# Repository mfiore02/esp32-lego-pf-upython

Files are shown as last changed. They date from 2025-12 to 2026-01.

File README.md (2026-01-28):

# ESP32 Lego Power Functions Controller

MicroPython implementation of a wireless Lego Power Functions motor controller system using ESP32-C3 and ESP-NOW.

## Overview

This project implements a low-latency wireless control system for Lego Power Functions motors, consisting of:

- **Handheld Controller**: Potentiometer for speed, button for direction toggle, 2xAA powered
- **Train Receiver**: Dual TB6612 motor driver, 2S LiPo with USB-C charging, fits in 8x4 stud Lego box
- **Communication**: ESP-NOW protocol for <10ms latency
- **Pairing**: Button-based pairing with MAC addresses stored in NVS flash

## System Architecture

```
┌─────────────────────┐                    ┌─────────────────────┐
│  CONTROLLER         │                    │  TRAIN RECEIVER     │
│  (Handheld)         │   ESP-NOW (WiFi)   │  (On Train)         │
├─────────────────────┤◄──────────────────►├─────────────────────┤
│ • Potentiometer     │   20Hz updates     │ • TB6612 Driver     │
│ • Direction Button  │   Low latency      │ • 2x Motors         │
│ • Status LED        │   Paired MAC       │ • Pair Button       │
│ • 2xAA Power        │   filtering        │ • 2S LiPo + BMS     │
└─────────────────────┘                    └─────────────────────┘
```

## Project Structure

```
esp32-lego-pf-upython/
├── lib/                          # Shared modules (both devices)
│   ├── espnow_protocol.py        # ESP-NOW wrapper + message protocol
│   ├── config_manager.py         # NVM storage abstraction (versioned)
│   ├── button.py                 # Debounced button driver
│   ├── led.py                    # LED patterns (solid, blink, etc)
│   ├── motor_driver.py           # TB6612 abstraction
│   ├── potentiometer.py          # ADC with dead zone handling
│   ├── battery.py                # 2S LiPo voltage monitoring (receiver)
│   └── hardware.py               # GPIO pin assignments (both devices)
│
├── controller/
│   ├── boot.py                   # Minimal - sets up path
│   └── main.py                   # Controller app entry point
│
├── receiver/
│   ├── boot.py                   # Minimal - sets up path
│   └── main.py                   # Receiver app entry point
│
├── tests/                        # Unit tests (run on host)
│   ├── test_espnow_protocol.py
│   ├── test_config_manager.py
│   └── test_potentiometer.py
│
├── hwil/                         # Hardware-in-loop test scripts
│   ├── test_button.py            # Flash to device, test button
│   ├── test_motors.py
│   └── test_espnow_ping.py
│
├── tools/
│   ├── flash_controller.sh       # Deploy to controller
│   ├── flash_receiver.sh         # Deploy to receiver
│   └── cli.py                    # USB-C serial config tool
│
├── docs/
│   └── lego_pf_controller_build_guide.pdf
│
└── README.md
```

## Hardware Requirements

### Train Receiver (Per-unit cost: $26-36)
- ESP32-C3 SuperMini
- TB6612FNG dual H-bridge motor driver
- USB-C 2S BMS (balanced charging)
- 2S LiPo 350mAh (45×15×14mm with balance lead)
- AMS1117-3.3V voltage regulator
- Mini slide switch (SPST, 3A+)
- Momentary pushbutton (or use onboard BOOT button)
- 2x Lego PF extension cables
- Prototype board and wiring

### Handheld Controller (Per-unit cost: $8-15)
- ESP32-C3 SuperMini
- 10K potentiometer (linear, panel mount)
- Knob for potentiometer
- Momentary pushbutton (direction + pairing)
- 2xAA battery holder
- SPST slide switch
- LED + 1K resistor
- Small project enclosure

See `docs/lego_pf_controller_build_guide.pdf` for detailed wiring diagrams and assembly instructions.

## GPIO Assignments

### Controller
| Function | GPIO | Notes |
|---|---|---|
| Potentiometer (ADC) | GPIO1 | Speed control |
| Status LED | GPIO8 | Status indicator |
| Direction Button | GPIO10 | Toggle direction + pairing mode |

### Receiver
| Function | GPIO | Notes |
|---|---|---|
| Motor 1 PWM | GPIO2 | TB6612 PWMA |
| Motor 1 IN1 | GPIO4 | TB6612 AIN1 |
| Motor 1 IN2 | GPIO3 | TB6612 AIN2 |
| Motor 2 PWM | GPIO5 | TB6612 PWMB |
| Motor 2 IN1 | GPIO7 | TB6612 BIN1 |
| Motor 2 IN2 | GPIO6 | TB6612 BIN2 |
| Status LED | GPIO8 | Status indicator |
| Pairing Button | GPIO10 | External button (active low) |
| Battery B+ (ADC) | GPIO0 | Full battery voltage via 100k/39k divider |
| Battery BM (ADC) | GPIO1 | Mid-point voltage via 33k/47k divider |

## Configuration Format

Configuration is stored in JSON format with versioning:

```json
{
  "version": 1,
  "device_type": "controller",
  "paired": true,
  "train_mac": [0x12, 0x34, 0x56, 0x78, 0x9A, 0xBC],
  "pot_calibration": {
    "min": 100,
    "max": 3995,
    "zero_band": 50
  }
}
```

## Development Workflow

This project follows an **incremental, test-driven development** approach:

1. Develop a module with clear interface
2. Write unit tests (where applicable)
3. Create HWIL test script
4. Validate on actual hardware
5. Move to next module

### Development Phases

#### Phase 1: Foundation Modules
1. ✅ `lib/config_manager.py` - NVM storage with versioning
2. ✅ `lib/button.py` - Debounced button input
3. ✅ `lib/led.py` - LED pattern control
4. ✅ `lib/potentiometer.py` - ADC with dead zone calibration
5. ✅ `lib/motor_driver.py` - TB6612 PWM control (hardware validated)

#### Phase 2: Communication Layer
6. ✅ `lib/espnow_protocol.py` - Message protocol and ESP-NOW wrapper (hardware validated)

#### Phase 3: Application Logic
7. ✅ `controller/main.py` - Controller application with pairing and control loop
8. ✅ `receiver/main.py` - Receiver application with motor control and safety timeout
9. ✅ End-to-end hardware validation and pairing flow testing (**SYSTEM WORKING!**)

#### Phase 4: Configuration & Deployment
10. ✅ Deployment scripts (controller, receiver, HWIL)
11. ⬜ `tools/cli.py` - USB-C serial configuration tool (optional)
12. ⬜ Final documentation and build guide updates

#### Phase 5: PCB Design
13. ✅ Controller schematic (P-FET power switching, GPIO assignments)
14. ✅ Receiver schematic (P-FET switching, TB6612 H-bridge, buck converter, BMS)
15. ✅ Custom symbol library (ESP32-C3-SuperMini, TB6612FNG, MP1584EN, 2S BMS)
16. ✅ Custom footprints (ESP32 module, slide switch, push button)
17. ⬜ Add decoupling capacitors to both schematics
18. ⬜ Custom footprints for breakout boards (2S BMS, MP1584EN buck, TB6612FNG)
19. ⬜ Controller PCB layout
20. ⬜ Receiver PCB layout

## Installation & Deployment

### Prerequisites
```bash
pip install esptool mpremote
```

### Flashing MicroPython Firmware
```bash
# Download ESP32-C3 firmware from micropython.org
# Erase flash
esptool.py --chip esp32c3 erase_flash

# Flash MicroPython
esptool.py --chip esp32c3 write_flash -z 0x0 ESP32_GENERIC_C3-*.bin
```

### Deploying Application Code

**Controller:**
```bash
./tools/flash_controller.sh /dev/ttyUSB0
```

**Receiver:**
```bash
./tools/flash_receiver.sh /dev/ttyUSB0
```

## Usage

### Pairing Procedure
1. Hold pairing button on train while powering on → motors twitch once
2. Hold direction button on controller while powering on → LED blinks rapidly
3. Wait 1-3 seconds → devices pair automatically
4. Train motors twitch twice, controller LED goes solid
5. Both devices reboot into normal mode

### Normal Operation
- **Speed**: Turn potentiometer (CCW=stop, CW=max)
- **Direction**: Press button to toggle forward/reverse
- **LED**: On=forward, Off=reverse
- **Safety**: Motors stop if no signal for 500ms

### Configuration via CLI
```bash
python tools/cli.py /dev/ttyUSB0

>>> config.show()
Paired: True
Train MAC: 12:34:56:78:9A:BC

>>> config.unpair()
Unpaired successfully
```

## Testing

### Unit Tests (Host)
```bash
python -m pytest tests/
```

### Hardware-in-Loop Tests
```bash
# Flash HWIL test to device (Windows example with COM port)
mpremote connect COM3 fs cp hwil/test_button.py :main.py

# Linux/Mac example
mpremote connect /dev/ttyUSB0 fs cp hwil/test_button.py :main.py

# Monitor serial output with mpremote
mpremote connect COM3 repl

# Or use screen on Linux/Mac
screen /dev/ttyUSB0 115200
```

## Safety Features

- 500ms communication timeout stops motors if signal lost
- BMS protection: overcharge, over-discharge, short-circuit
- Paired MAC filtering prevents unauthorized control
- Motor safety stop on receiver boot

## Future Enhancements

- [x] Battery level monitoring (`lib/battery.py` — voltage, per-cell, status, percentage)
- [ ] Battery telemetry (receiver → controller over ESP-NOW)
- [ ] Multiple train support (train selector on controller)
- [ ] Speed limit profiles (parental controls)
- [ ] Additional GPIO features (lights, sound effects)
- [ ] Remote configuration over ESP-NOW
- [ ] Web-based configuration interface

## License

See [LICENSE](LICENSE) file for details.

## References

- Build guide: `docs/lego_pf_controller_build_guide.pdf`
- ESP-NOW documentation: https://docs.espressif.com/projects/esp-idf/en/latest/esp32c3/api-reference/network/esp_now.html
- MicroPython ESP32: https://docs.micropython.org/en/latest/esp32/quickref.html

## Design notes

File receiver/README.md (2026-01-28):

# Receiver Application

Train receiver firmware for ESP32-C3.

## Files

- `boot.py` - Minimal boot script, sets up sys.path to include lib/
- `main.py` - Main application logic (pairing and normal mode)

GPIO pin assignments are centralized in [lib/hardware.py](../lib/hardware.py).

## Hardware

- **Motor 1 (TB6612 Channel A):**
  - PWM: GPIO2 (PWMA)
  - IN1: GPIO4 (AIN1)
  - IN2: GPIO3 (AIN2)

- **Motor 2 (TB6612 Channel B):**
  - PWM: GPIO5 (PWMB)
  - IN1: GPIO7 (BIN1)
  - IN2: GPIO6 (BIN2)

- **Battery Monitoring (2S LiPo via voltage dividers):**
  - B+ (full battery): GPIO0, 100k/39k divider (8.4V → 2.36V max)
  - BM (mid-point): GPIO1, 33k/47k divider (4.2V → 2.47V max)

- **Other I/O:**
  - Status LED: GPIO8 (status indicator, active high)
  - Pairing button: GPIO10 (external button, active low with pull-up)

- **Power:**
  - 2S LiPo battery (7.4V nominal) with USB-C charging via BMS
  - MP1584EN buck converter: Battery → 5V → ESP32 VIN pin
  - **Important:** Add 100-470µF bulk capacitor on motor driver power input

See main README.md for detailed GPIO assignments, motor driver wiring, and power system design.

## Operation Modes

1. **Pairing Mode**: Hold button during power-on to pair with a controller
2. **Normal Mode**: Receives control messages and drives motors with 125ms safety timeout

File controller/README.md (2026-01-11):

# Controller Application

Handheld controller firmware for ESP32-C3.

## Files

- `boot.py` - Minimal boot script, sets up sys.path to include lib/
- `main.py` - Main application logic (pairing and normal mode)

GPIO pin assignments are centralized in [lib/hardware.py](../lib/hardware.py).

## Hardware

- Potentiometer on GPIO1 (speed control, ADC)
- Direction button on GPIO10 (toggle + pairing trigger, active low with pull-up)
- Status LED on GPIO8 (direction indicator, active high)
- Power: 3x AA batteries (4.5V recommended) or 2x AA with boost converter to 5V
  - **Do NOT connect batteries directly to 3.3V pin!**
  - Connect to 5V/VIN pin on ESP32-C3

See main README.md for detailed GPIO assignments and hardware requirements.

## Operation Modes

1. **Pairing Mode**: Hold button during power-on to pair with a train
2. **Normal Mode**: Standard operation, sends control messages at 20Hz (50ms interval)

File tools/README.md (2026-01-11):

# Development Tools

Deployment and configuration utilities.

## Scripts

### deploy_controller.sh
Deploys controller firmware to ESP32-C3.

```bash
# Windows
.\tools\deploy_controller.sh COM3

# Linux/Mac
./tools/deploy_controller.sh /dev/ttyUSB0
```

### deploy_receiver.sh
Deploys receiver firmware to ESP32-C3.

```bash
# Windows
.\tools\deploy_receiver.sh COM3

# Linux/Mac
./tools/deploy_receiver.sh /dev/ttyUSB0
```

### deploy_hwil.sh
Deploys HWIL tests for hardware validation.

```bash
# Windows
.\tools\deploy_hwil.sh COM3

# Linux/Mac
./tools/deploy_hwil.sh /dev/ttyUSB0
```

### cli.py
Interactive serial-based configuration tool for devices.

```bash
# Windows
python tools/cli.py COM3

# Linux/Mac
python tools/cli.py /dev/ttyUSB0
```

Example session:
```
>>> config.show()                           # Display entire config
>>> config.get('paired')                    # Get specific value
>>> config.set('pot_calibration.min', 150)  # Set and auto-save
>>> config.unpair()                         # Clear pairing data
>>> help                                    # Show all commands
>>> exit()                                  # Exit CLI
```

Automatically detects device type (controller or receiver).

## Requirements

```bash
pip install esptool mpremote
```

## Documentation

See [MPREMOTE_GUIDE.md](MPREMOTE_GUIDE.md) for detailed mpremote usage examples and manual deployment instructions.

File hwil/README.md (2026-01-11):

# Hardware-in-Loop Tests

Test scripts designed to be flashed directly to ESP32 devices for validation.

## Usage

Use the deployment script (easiest):

```bash
# Windows
.\tools\deploy_hwil.sh COM3

# Linux/Mac
./tools/deploy_hwil.sh /dev/ttyUSB0
```

Or manually with mpremote:

```bash
# Flash a HWIL test to device as main.py
mpremote connect /dev/ttyUSB0 fs cp hwil/test_button_hwil.py :main.py
mpremote connect /dev/ttyUSB0 fs cp lib/button.py :/lib/button.py

# Monitor serial output
mpremote connect /dev/ttyUSB0 repl
```

## Test Scripts

- `test_button_hwil.py` - Verify button debouncing and edge detection
- `test_led_hwil.py` - LED pattern timing validation
- `test_potentiometer_hwil.py` - ADC reading and calibration helper
- `test_motor_driver_hwil.py` - Test motor control (PWM, direction, reversal)
- `test_espnow_protocol_hwil.py` - Two-device communication test (pairing, ping/pong)
- `test_config_manager_hwil.py` - Filesystem persistence validation across reboots

Each test script is standalone and prints results to the serial console.

## Documentation

- See `tools/deploy_hwil.sh` for automated deployment script
- See `tools/MPREMOTE_GUIDE.md` for detailed mpremote usage examples
- See `HWIL_AUDIT_REPORT.md` for GPIO mapping verification and test coverage analysis

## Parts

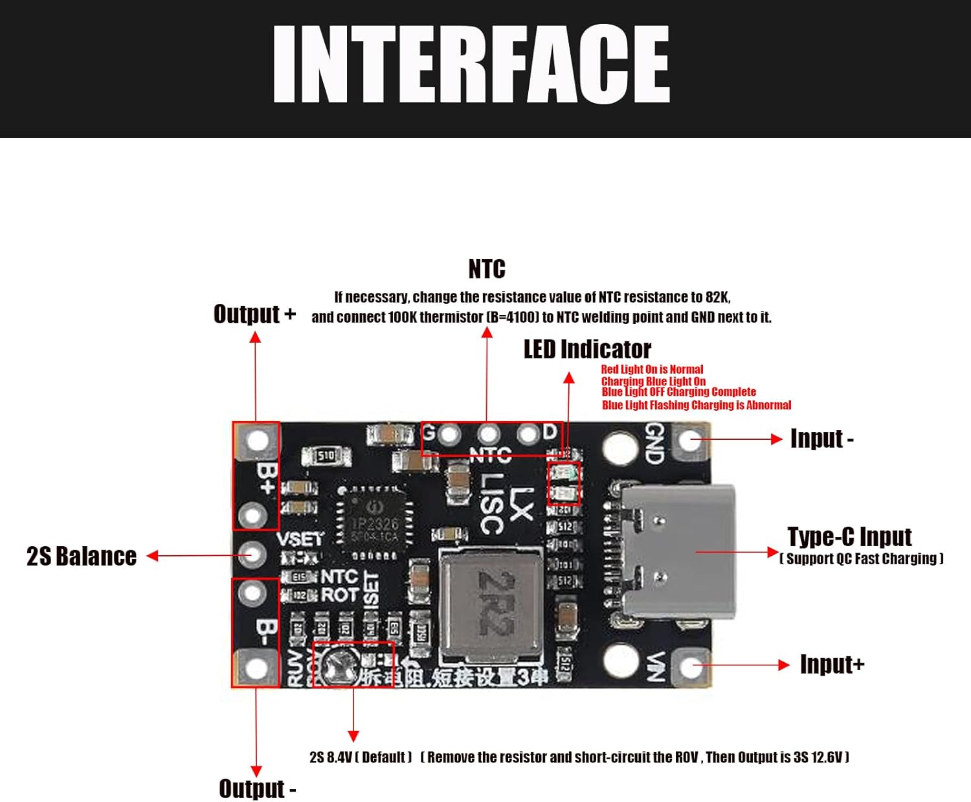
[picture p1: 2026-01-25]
bom/images/2S_BMS.jpg

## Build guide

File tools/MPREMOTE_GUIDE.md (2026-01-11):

# mpremote Quick Reference Guide

`mpremote` is the official MicroPython remote control tool for interacting with ESP32 devices.

## Basic Commands

### Connect to Device

**Windows:**
```bash
mpremote connect COM3
```

**Linux/Mac:**
```bash
mpremote connect /dev/ttyUSB0
```

### File Operations

**Copy file to device:**
```bash
# Copy to root
mpremote connect COM3 fs cp local_file.py :remote_file.py

# Copy to /lib directory
mpremote connect COM3 fs cp lib/module.py :/lib/module.py
```

**Copy file from device:**
```bash
mpremote connect COM3 fs cp :remote_file.py local_file.py
```

**List files on device:**
```bash
mpremote connect COM3 fs ls
mpremote connect COM3 fs ls :/lib
```

**Remove file from device:**
```bash
mpremote connect COM3 fs rm :file.py
```

**Create directory:**
```bash
mpremote connect COM3 fs mkdir /lib
```

### Device Control

**Reset device:**
```bash
mpremote connect COM3 reset
```

**Enter REPL (interactive Python):**
```bash
mpremote connect COM3 repl
# Press Ctrl+] to exit REPL
```

**Run a Python command:**
```bash
mpremote connect COM3 exec "print('Hello from ESP32')"
mpremote connect COM3 exec "import machine; print(machine.unique_id())"
```

**Run a local Python script on device:**
```bash
mpremote connect COM3 run script.py
```

### Filesystem Management

**Show disk usage:**
```bash
mpremote connect COM3 fs df
```

**Erase all files (careful!):**
```bash
mpremote connect COM3 fs rmdir :
```

## Deployment Workflow for this Project

### Deploy HWIL Test (Easy Way)

**Windows:**
```bash
.\tools\deploy_hwil_test.bat COM3 test_config_manager
mpremote connect COM3 repl
```

**Linux/Mac:**
```bash
./tools/deploy_hwil_test.sh /dev/ttyUSB0 test_config_manager
mpremote connect /dev/ttyUSB0 repl
```

### Deploy HWIL Test (Manual)

```bash
# 1. Create lib directory
mpremote connect COM3 fs mkdir /lib

# 2. Copy required library
mpremote connect COM3 fs cp lib/config_manager.py :/lib/config_manager.py

# 3. Copy test as main.py
mpremote connect COM3 fs cp hwil/test_config_manager.py :main.py

# 4. Reset and monitor
mpremote connect COM3 reset
mpremote connect COM3 repl
```

### Deploy Application Code

**Controller:**
```bash
# Copy shared libraries
mpremote connect COM3 fs mkdir /lib
mpremote connect COM3 fs cp lib/config_manager.py :/lib/config_manager.py
mpremote connect COM3 fs cp lib/button.py :/lib/button.py
mpremote connect COM3 fs cp lib/led.py :/lib/led.py
mpremote connect COM3 fs cp lib/potentiometer.py :/lib/potentiometer.py
mpremote connect COM3 fs cp lib/espnow_protocol.py :/lib/espnow_protocol.py
mpremote connect COM3 fs cp lib/hardware.py :/lib/hardware.py

# Copy controller app
mpremote connect COM3 fs cp controller/boot.py :boot.py
mpremote connect COM3 fs cp controller/main.py :main.py

# Reset
mpremote connect COM3 reset
```

**Receiver:**
```bash
# Copy shared libraries
mpremote connect COM3 fs mkdir /lib
mpremote connect COM3 fs cp lib/config_manager.py :/lib/config_manager.py
mpremote connect COM3 fs cp lib/button.py :/lib/button.py
mpremote connect COM3 fs cp lib/motor_driver.py :/lib/motor_driver.py
mpremote connect COM3 fs cp lib/espnow_protocol.py :/lib/espnow_protocol.py
mpremote connect COM3 fs cp lib/hardware.py :/lib/hardware.py

# Copy receiver app
mpremote connect COM3 fs cp receiver/boot.py :boot.py
mpremote connect COM3 fs cp receiver/main.py :main.py

# Reset
mpremote connect COM3 reset
```

## Troubleshooting

### Find COM Port (Windows)
Check Device Manager → Ports (COM & LPT) → USB-SERIAL CH340

Or use PowerShell:
```powershell
Get-WmiObject Win32_SerialPort | Select-Object Name,DeviceID
```

### Find Device Port (Linux)
```bash
ls /dev/ttyUSB*
# or
ls /dev/ttyACM*
```

### Find Device Port (Mac)
```bash
ls /dev/cu.usbserial-*
# or
ls /dev/cu.wchusbserial*
```

### Permission Denied (Linux)
```bash
# Add user to dialout group
sudo usermod -a -G dialout $USER
# Log out and back in

# Or use sudo
sudo mpremote connect /dev/ttyUSB0 repl
```

### Device Not Responding
1. Check USB cable (must be data cable, not charge-only)
2. Press RESET button on ESP32
3. Try different USB port
4. Unplug and replug device

### REPL Not Responding
Press Ctrl+C to interrupt running program, then Ctrl+D for soft reset

## Useful mpremote Tips

**Chain commands:**
```bash
mpremote connect COM3 fs cp test.py :main.py + reset + repl
```

**Use shortcuts:**
```bash
# Auto-detect port (if only one device connected)
mpremote fs ls

# Set default connection
export MPREMOTE_DEVICE=/dev/ttyUSB0
mpremote fs ls
```

**Mount local filesystem (advanced):**
```bash
mpremote connect COM3 mount .
# Device can now import modules from current directory
```

## References

- Official mpremote docs: https://docs.micropython.org/en/latest/reference/mpremote.html
- MicroPython ESP32 guide: https://docs.micropython.org/en/latest/esp32/quickref.html

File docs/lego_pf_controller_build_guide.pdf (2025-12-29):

# Lego Power Functions Wireless Control System

# Build Guide

Component | Description
Train Receiver | 1-2 motor controller, 2S LiPo, USB-C charging
Handheld Controller | Knob speed, button direction, AA batteries
Communication | ESP-NOW (WiFi-based, low latency)
Pairing | Button-based, configs saved to NVS flash
Enclosure | Train: 8×4 stud Lego box, Controller: project box

# Version 1.1 — December 2024

# Part 1: Train Receiver

# Parts List

Part | Description | Qty | Price
ESP32-C3 SuperMini | Microcontroller with WiFi/BLE | 1 | $2-4
TB6612FNG Module | Dual H-bridge motor driver | 1 | $3-5
USB-C 2S BMS (balanced) | Charger + balancer + protection | 1 | $2-3
2S LiPo 350mAh | 45×15×14mm, with balance lead | 1 | $8-12
AMS1117-3.3 Module | 3.3V voltage regulator | 1 | $0.50-1
Mini Slide Switch | SPST power switch, 3A+ rated | 1 | $0.50
Momentary Pushbutton | Pairing button (or use onboard BOOT) | 1 | $0.20-0.50
Lego PF Extension Cable | Cut & splice for connectors | 2 | $2-4 ea
Prototype board / wires | For assembly | 1 | $2-3

# Estimated Total: $26-36

Note: Many ESP32-C3 SuperMini boards have a BOOT button on GPIO9 — you can use that for pairing instead of adding an external button. Check your board first.

# Suggested Sources

## - ESP32-C3 SuperMini: AliExpress, Amazon - TB6612FNG Module: SparkFun, Pololu, AliExpress - USB-C 2S BMS: AliExpress (search "Type-C USB 2S BMS balanced") - 2S LiPo: Amazon, AliExpress (must have 3-pin balance connector) - PF Extension Cables: BrickLink, AliExpress, or official Lego

# System Architecture

■■■■■■■■■■■■■■■■■■
USB-C 5V ■■■■■■■■■■■ | 2S BMS Module ■
■ | (balanced) | ■
■■■■■■■■■■■■■■■■■■
| ■
B+ / BAL / B- (white 3-pin JST-XH)
| ■
■■■■■■■■▼■■■■■■■■■
■ | 2S LiPo | ■
■ | 350mAh | ■
■■■■■■■■■■■■■■■■■■
| ■
P+ / P- (protected output)
| ■
■■■■■■■■▼■■■■■■■■■
■ Power Switch ■
■■■■■■■■■■■■■■■■■■
| ■
■■■■■■■■■■■■■■■■■■■■■■■■■■■■■■■■■■■■■■■■■■■■■■■■■■■

■ | ■ | ■
▼ | ▼ | ▼
■■■■■■■■■■■■ | ■■■■■■■■■■■■ | ■■■■■■■■■■■■
■ AMS1117 ■ | ■ TB6612 | ■ | ■ TB6612 | ■
■ | 3.3V | ■ | ■ Motor 1 ■ | ■ Motor 2 ■
■■■■■■■■■■■■ | ■■■■■■■■■■■■ | ■■■■■■■■■■■■
■ | ■ | ■
▼ | ▼ | ▼
ESP32-C3 ■■■ [PAIR BTN] PF Motor 1 | PF Motor 2

# GPIO Assignments

Function | GPIO | Notes
Motor 1 PWM | GPIO2 | Speed control
Motor 1 Direction | GPIO3 | TB6612 AIN1
Motor 2 PWM | GPIO4 | Speed control
Motor 2 Direction | GPIO5 | TB6612 BIN1
Pairing Button | GPIO9 | BOOT button on most boards

# Wiring Connections

# Power Wiring

From | To | Notes
Battery 3-pin JST-XH | BMS: B+, BAL, B- | White connector
BMS P+ | Switch input | Red wire
BMS P- | Common GND rail | Black wire
Switch output | TB6612 VM | Switched battery power
Switch output | AMS1117 VIN | Switched battery power
AMS1117 VOUT | ESP32 3V3 | 3.3V regulated
AMS1117 VOUT | TB6612 VCC | 3.3V logic power
AMS1117 VOUT | TB6612 STBY | Enable driver
GND | All GND pins | Common ground

# Control Signal Wiring

From | To | Notes
ESP32 GPIO2 | TB6612 PWMA | Motor 1 speed (PWM)
ESP32 GPIO3 | TB6612 AIN1 | Motor 1 direction
GND | TB6612 AIN2 | Tie to ground
ESP32 GPIO4 | TB6612 PWMB | Motor 2 speed (PWM)
ESP32 GPIO5 | TB6612 BIN1 | Motor 2 direction
GND | TB6612 BIN2 | Tie to ground
Pair Button | ESP32 GPIO9 | Or use onboard BOOT button
Pair Button | GND | Other side of button

# Motor Output Wiring

From | To | Notes

TB6612 AO1 | PF Cable 1 - C1 | Motor 1 +
TB6612 AO2 | PF Cable 1 - C2 | Motor 1 -
TB6612 BO1 | PF Cable 2 - C1 | Motor 2 +
TB6612 BO2 | PF Cable 2 - C2 | Motor 2 -

# Lego PF Cable Pinout

When cutting a PF extension cable, keep the end that plugs into the motor. Use a multimeter to identify the wires — colors vary by manufacturer.

Pin | Signal | Connect To
1 | 9V | Not used
2 | C1 | TB6612 xO1
3 | C2 | TB6612 xO2
4 | GND | Common GND

# Assembly Steps

# 1. Prepare the PF Cables

Cut the PF extension cable, keeping the motor end. Strip wires and identify C1, C2, GND with a multimeter.

# 2. Wire the Power Section

Connect battery balance lead to BMS. Connect BMS P+ to switch, switch output to TB6612 VM and AMS1117 VIN.

# 3. Wire the ESP32

Connect 3.3V rail to ESP32 3V3, GND to ESP32 GND. Verify power before proceeding.

# 4. Wire the TB6612

VM to battery, VCC and STBY to 3.3V, AIN2/BIN2 to GND. Connect control signals from ESP32.

# 5. Add Pairing Button

Connect button between GPIO9 and GND (or use onboard BOOT button if available).

# 6. Wire the Motors

Connect AO1/AO2 to Motor 1 C1/C2. Connect BO1/BO2 to Motor 2 C1/C2.

# 7. Test

Verify voltages, upload firmware, test pairing and motor control.

# Part 2: Handheld Controller

A simple handheld controller with a knob for speed and a button to toggle direction. Powered by 2×AA batteries for simplicity — no charging required. The same button is used for direction toggle (short press) and pairing mode (hold on boot).

# Parts List

Part | Description | Qty | Price
ESP32-C3 SuperMini | Microcontroller with WiFi/BLE | 1 | $2-4
10K Potentiometer | Linear taper, panel mount | 1 | $1-2
Knob | For potentiometer shaft | 1 | $0.50-1
Momentary Pushbutton | Direction toggle + pairing | 1 | $0.50-1
2×AA Battery Holder | 3V power source | 1 | $1-2
Slide Switch (SPST) | Power on/off | 1 | $0.50
LED + 1K Resistor | Direction indicator | 1 | $0.20
Project Box | Small enclosure | 1 | $2-5

# Estimated Total: $8-15

# Schematic

2×AA Batteries (3V)
■
■■■■■■▼■■■■■■
■ | Switch | ■
■■■■■■■■■■■■■
■
■■■■■■■■■■■■■■■■■■■■■■■■■■■■
■ | ■
▼ | ■
■■■■■■■■■■■■■■■■■ | ■
■ | ESP32-C3 | ■ | ■
■ | ■ | ■
■ 3V3 ■■■■■■■■■■■■■■■■■■■■■■■■■■■■■■
■ | ■ | ■
■ GND ■■■■■■■■■■■■■■■■■■■■■■■■■■■■■■■■■■
■ | ■ | ■ | ■
■ GPIO0 (ADC) ■■■■■ POT wiper | ■ | ■
■ | ■ | ■ | ■
■ GPIO1 ■■■■■■■■■■■ Button ■■■■■■■■■■■■■ | (direction + pairing)
■ | ■ | ■ | ■
■ GPIO2 ■■■■■■■■■■■ LED ■■[1K]■■■■■■■■■■
■ | ■ | ■ | ■
■■■■■■■■■■■■■■■■■ | ■ | ■
■ | ■
POT: Pin 1 to GND ■■■■■■■■■■■■■■■ Pin 3 to 3V3 ■■■■■■■■■■■ ■ ■
All GND ■■■■■■

# Wiring Connections

From | To | Notes
Battery + | Switch input | Red wire
Switch output | ESP32 3V3 | Switched power
Battery - | ESP32 GND | Common ground
Pot pin 1 | GND | Ground reference
Pot pin 2 (wiper) | ESP32 GPIO0 | Analog input
Pot pin 3 | 3V3 | Voltage reference
Button pin 1 | ESP32 GPIO1 | Direction + pairing
Button pin 2 | GND | Uses internal pull-up
LED anode | ESP32 GPIO2 | Through 1K resistor
LED cathode | GND

# Assembly Steps

# 1. Prepare the Enclosure

Drill holes for potentiometer, button, power switch, and LED.

# 2. Mount Components

Install pot, button, switch, and LED in the enclosure.

# 3. Wire Power

Connect battery holder through switch to ESP32 3V3 and GND.

# 4. Wire Controls

Connect pot wiper to GPIO0, button to GPIO1, LED to GPIO2.

# 5. Install Battery Holder

Secure inside enclosure with double-sided tape or screws.

# 6. Test

Verify pot reads 0-4095, button toggles LED, pairing mode works.

# Operation

## - Speed: Turn knob — full CCW = stop, full CW = max speed - Direction: Short press button to toggle forward/reverse - LED: On = forward, Off = reverse - Pairing: Hold button while turning on power (see Part 4)

# Part 3: Pairing Mode

Both devices store their paired partner's MAC address in non-volatile storage (NVS). Once paired, they remember each other across power cycles — no need to pair again unless you want to switch to a different train or controller.

# Pairing Procedure

# 1. Put Train in Pairing Mode

Hold the pairing button (GPIO9 / BOOT) while turning on the train. Motors will twitch briefly to confirm pairing mode.

# 2. Put Controller in Pairing Mode

Hold the direction button while turning on the controller. LED will blink rapidly to confirm pairing mode.

# 3. Wait for Pairing

Devices will find each other automatically (1-3 seconds). Train motors twitch twice, controller LED goes solid when paired.

# 4. Done!

Both devices save the pairing and reboot into normal mode. They will reconnect automatically on future power-ups.

# Pairing Flow Diagram

CONTROLLER | | TRAIN
■ | | ■
[Hold button | | [Hold button
+ power on] | | + power on]
■ | | ■
▼ | | ▼
■■■■■■■■■■■■■■■ | ■■■■■■■■■■■■■■■
■ PAIRING | ■ | ■ PAIRING | ■
■ MODE | ■ | ■ MODE | ■
■ (LED blink) ■ | ■ (motor twitch)
■■■■■■■■■■■■■■■ | ■■■■■■■■■■■■■■■
■ | | ■
■ | ■■ PAIR_REQUEST (broadcast) ■■■ | ■
■ | | ■
■ | ■■■ PAIR_ACK + train MAC ■■■■■ | ■
■ | | ■
■ | ■■ PAIR_CONFIRM + ctrl MAC ■■■ | ■
■ | | ■
▼ | | ▼
■■■■■■■■■■■■■■■ | ■■■■■■■■■■■■■■■
■ Save train ■ | ■ Save ctrl | ■
■ MAC to NVS ■ | ■ MAC to NVS ■
■■■■■■■■■■■■■■■ | ■■■■■■■■■■■■■■■
■ | | ■
▼ | | ▼
[Reboot] | | [Reboot]
■ | | ■
▼ | | ▼
■■■■■■■■■■■■■■■ | ■■■■■■■■■■■■■■■
■ NORMAL MODE ■ ■■■■■■■■■■■■■■■■■■■■■ ■ NORMAL MODE ■ ■ (LED solid) ■ speed + direction ■ (motors run)■

■■■■■■■■■■■■■■■ | ■■■■■■■■■■■■■■■

# Stored Configuration

## The following settings are saved to NVS flash and persist across power cycles:

Device | Setting | Description
Train | Controller MAC | Only accepts commands from this controller
Train | Motor 1 Invert | Flip motor 1 direction (future feature)
Train | Motor 2 Invert | Flip motor 2 direction (future feature)
Train | Max Speed | Speed limit 0-255 (future feature)
Controller | Train MAC | Sends commands to this train only

# Part 4: Firmware

Both units use ESP-NOW for communication — a fast, connectionless protocol. Pairing info and config are stored in NVS flash.

# Controller Firmware

#include <esp_now.h>

#include <WiFi.h>

#include <Preferences.h>

#define POT_PIN | 0

#define BTN_PIN | 1

#define LED_PIN | 2

Preferences prefs;
uint8_t trainMAC[6] = {0xFF,0xFF,0xFF,0xFF,0xFF,0xFF}; bool paired = false;
bool forward = true;
bool pairingMode = false;

enum MsgType { MSG_CONTROL, MSG_PAIR_REQ, MSG_PAIR_ACK, MSG_PAIR_CONFIRM };

typedef struct {
uint8_t type;
uint8_t speed;
bool forward;
uint8_t mac[6];
} Message;

Message msg;

void loadConfig() {
prefs.begin("ctrl", false);
if (prefs.getBool("paired", false)) { paired = true;
trainMAC[0] = prefs.getUChar("mac0", 0xFF); trainMAC[1] = prefs.getUChar("mac1", 0xFF); trainMAC[2] = prefs.getUChar("mac2", 0xFF); trainMAC[3] = prefs.getUChar("mac3", 0xFF); trainMAC[4] = prefs.getUChar("mac4", 0xFF); trainMAC[5] = prefs.getUChar("mac5", 0xFF); }
}

void saveTrainMAC(uint8_t *mac) {
prefs.putBool("paired", true);
prefs.putUChar("mac0", mac[0]); prefs.putUChar("mac1", mac[1]); prefs.putUChar("mac2", mac[2]); prefs.putUChar("mac3", mac[3]); prefs.putUChar("mac4", mac[4]); prefs.putUChar("mac5", mac[5]);
}

void onReceive(const esp_now_recv_info_t *info, const uint8_t *data, int len) { if (len < 1) return;
Message *m = (Message*)data;
if (pairingMode && m->type == MSG_PAIR_ACK) {
memcpy(trainMAC, m->mac, 6); saveTrainMAC(trainMAC);
// Send confirm
msg.type = MSG_PAIR_CONFIRM; WiFi.macAddress(msg.mac);
esp_now_send(trainMAC, (uint8_t*)&msg, sizeof(msg)); delay(100);
ESP.restart();
}
}

void setup() {
pinMode(BTN_PIN, INPUT_PULLUP); pinMode(LED_PIN, OUTPUT);

// Check for pairing mode (button held at boot) if (digitalRead(BTN_PIN) == LOW) { pairingMode = true;
}

loadConfig();

WiFi.mode(WIFI_STA);
esp_now_init();
esp_now_register_recv_cb(onReceive);

// Add peer (broadcast for pairing, specific MAC for normal) esp_now_peer_info_t peer = {};
memcpy(peer.peer_addr, trainMAC, 6);
peer.channel = 0;
peer.encrypt = false;
esp_now_add_peer(&peer);

if (pairingMode) {
// Blink LED rapidly in pairing mode for(int i=0; i<10; i++) {
digitalWrite(LED_PIN, i%2); delay(100);
}
}
digitalWrite(LED_PIN, forward); }

bool lastBtn = HIGH;
unsigned long lastSend = 0;

void loop() {
// Pairing mode: send pair requests
if (pairingMode) {
digitalWrite(LED_PIN, (millis()/100) % 2); // Fast blink msg.type = MSG_PAIR_REQ;
WiFi.macAddress(msg.mac);
uint8_t broadcast[6] = {0xFF,0xFF,0xFF,0xFF,0xFF,0xFF}; esp_now_send(broadcast, (uint8_t*)&msg, sizeof(msg)); delay(200);
return;
}

// Normal mode
int raw = analogRead(POT_PIN); msg.type = MSG_CONTROL;
msg.speed = map(raw, 0, 4095, 0, 255);

bool btn = digitalRead(BTN_PIN);
if (btn == LOW && lastBtn == HIGH) { forward = !forward;
digitalWrite(LED_PIN, forward); }
lastBtn = btn;
msg.forward = forward;

if (millis() - lastSend > 50) { esp_now_send(trainMAC, (uint8_t*)&msg, sizeof(msg)); lastSend = millis();
}
}

# Train Receiver Firmware

#include <esp_now.h>

#include <WiFi.h>

#include <Preferences.h>

#define M1_PWM 2

#define M1_DIR 3

#define M2_PWM 4

#define M2_DIR 5

#define PAIR_BTN 9

Preferences prefs;
uint8_t ctrlMAC[6] = {0xFF,0xFF,0xFF,0xFF,0xFF,0xFF}; bool paired = false;
bool pairingMode = false;
unsigned long lastRecv = 0;

enum MsgType { MSG_CONTROL, MSG_PAIR_REQ, MSG_PAIR_ACK, MSG_PAIR_CONFIRM };

typedef struct {
uint8_t type;
uint8_t speed;
bool forward;
uint8_t mac[6];
} Message;

Message msg;

void loadConfig() {
prefs.begin("train", false);
if (prefs.getBool("paired", false)) { paired = true;
ctrlMAC[0] = prefs.getUChar("mac0", 0xFF); ctrlMAC[1] = prefs.getUChar("mac1", 0xFF); ctrlMAC[2] = prefs.getUChar("mac2", 0xFF); ctrlMAC[3] = prefs.getUChar("mac3", 0xFF); ctrlMAC[4] = prefs.getUChar("mac4", 0xFF); ctrlMAC[5] = prefs.getUChar("mac5", 0xFF); }
}

void saveCtrlMAC(uint8_t *mac) {
prefs.putBool("paired", true);
prefs.putUChar("mac0", mac[0]); prefs.putUChar("mac1", mac[1]); prefs.putUChar("mac2", mac[2]); prefs.putUChar("mac3", mac[3]); prefs.putUChar("mac4", mac[4]); prefs.putUChar("mac5", mac[5]); }

void setMotor(int pwm, int dir, uint8_t speed, bool fwd) { digitalWrite(dir, fwd ? HIGH : LOW);
analogWrite(pwm, speed);
}

void motorTwitch(int count) {
for(int i=0; i<count; i++) { setMotor(M1_PWM, M1_DIR, 100, true); delay(100);
setMotor(M1_PWM, M1_DIR, 0, true); delay(100);
}
}

void onReceive(const esp_now_recv_info_t *info, const uint8_t *data, int len) { if (len < 1) return;
Message *m = (Message*)data;

if (pairingMode && m->type == MSG_PAIR_REQ) {
// Send ACK with our MAC
msg.type = MSG_PAIR_ACK;
WiFi.macAddress(msg.mac);
esp_now_send(info->src_addr, (uint8_t*)&msg, sizeof(msg)); }
else if (pairingMode && m->type == MSG_PAIR_CONFIRM) { memcpy(ctrlMAC, m->mac, 6);
saveCtrlMAC(ctrlMAC);
motorTwitch(2); // Confirm pairing
delay(500);
ESP.restart();
}
else if (!pairingMode && m->type == MSG_CONTROL) {
// In normal mode, only accept from paired controller if (paired && memcmp(info->src_addr, ctrlMAC, 6) != 0) return; setMotor(M1_PWM, M1_DIR, m->speed, m->forward); setMotor(M2_PWM, M2_DIR, m->speed, m->forward);
lastRecv = millis();
}
}

void setup() {
pinMode(M1_PWM, OUTPUT); pinMode(M1_DIR, OUTPUT); pinMode(M2_PWM, OUTPUT); pinMode(M2_DIR, OUTPUT); pinMode(PAIR_BTN, INPUT_PULLUP);

if (digitalRead(PAIR_BTN) == LOW) {
pairingMode = true;
}

loadConfig();

WiFi.mode(WIFI_STA);
esp_now_init();
esp_now_register_recv_cb(onReceive);

if (pairingMode) {
motorTwitch(1); // Signal pairing mode }
}

void loop() {
// Safety: stop if no signal for 500ms
if (!pairingMode && millis() - lastRecv > 500) { setMotor(M1_PWM, M1_DIR, 0, true); setMotor(M2_PWM, M2_DIR, 0, true);
}
delay(20);
}

# Firmware Upload Instructions

## 1. Install Arduino IDE and add ESP32 board support: File → Preferences → Additional Board URLs:

https://raw.githubusercontent.com/espressif/arduino-esp32/gh-pages/package_esp32_index.json

## 2. Select board: Tools → Board → ESP32C3 Dev Module

## 3. Upload train firmware first — note: upload order doesn't matter for pairing

# 4. Upload controller firmware

# 5. Follow pairing procedure (Part 3) to link the devices

# Troubleshooting

Problem | Possible Cause | Solution
No power (train) | Switch off, dead battery | Check switch, charge via USB-C
No power (controller) | Dead batteries, switch off | Replace AA batteries
Pairing fails | Not in pairing mode | Hold button WHILE powering on
Pairing fails | Out of range | Move devices closer together
Motor not spinning | Wrong wiring, STBY low | Verify connections, STBY to 3.3V
Wrong direction | C1/C2 swapped | Swap AO1/AO2 wires
Train stops randomly | Signal lost > 500ms | Check controller batteries, range
Unpaired after reboot | NVS not saving | Re-pair, check for code errors

# Safety Notes

## - LiPo batteries can be dangerous — never puncture, short, or overcharge

## - Always use the BMS — provides overcharge, over-discharge, and short-circuit protection

## - Don't leave charging unattended — especially during initial tests

## - Disconnect battery when making wiring changes

## - Check polarity before connecting anything

## - Supervise children when using the controller

# Runtime Estimates

# Train Receiver (350mAh 2S LiPo):

Load | Current | Runtime
1 motor, light | ~100mA | ~3+ hours
2 motors, moderate | ~300mA | ~1 hour
2 motors, heavy | ~500mA | ~40 min

## Controller (2×AA): 20-40+ hours typical (low power between transmits)

# Expansion Options

## - 4 motors: Add second TB6612FNG, use GPIO6/7/8/10 - Multiple trains: Add train select button to controller, store multiple MACs - Lights/sound: Use spare GPIOs on train receiver - Phone app: Replace controller with BLE smartphone app - Speed limit: Add max speed config in NVS for younger kids

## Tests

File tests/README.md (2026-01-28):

# Unit Tests

Host-based unit tests for shared library modules.

## Running Tests

```bash
python -m pytest tests/
```

## Test Coverage

- `test_button.py` - Button debouncing and edge detection logic
- `test_config_manager.py` - Configuration storage, versioning, and migration
- `test_espnow_protocol.py` - Message encoding/decoding and protocol logic
- `test_led.py` - LED pattern timing and state management
- `test_motor_driver.py` - Motor control logic, reversal, and safety features
- `test_potentiometer.py` - Dead zone calibration and ADC value mapping
- `test_battery.py` - Battery voltage conversion, status thresholds, and percentage calculation

All unit tests run on host Python (no hardware required).
Hardware validation tests are in the `hwil/` directory.

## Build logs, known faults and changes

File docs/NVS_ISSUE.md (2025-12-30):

# NVS Testing Issue (Resolved)

## Summary

During development, we initially thought ESP32 NVS had persistence issues. **This was actually a testing methodology problem**, not an NVS bug. NVS likely works fine.

## The Testing Bug

Our initial tests had **auto-cleanup** that ran too early:

1. **Hard reboot**: ESP32 boots, test runs automatically
2. **Test finds persisted data**: Prints "SUCCESS!"
3. **Test auto-cleans up**: Erases data immediately
4. **We connect to REPL**: Data already gone
5. **We soft reset**: Sees no data, starts over

**Result**: We never saw the SUCCESS message, assumed NVS was broken!

## Actual Status

- ✅ **NVS probably works fine** (untested after fixing the test bug)
- ✅ **Filesystem definitely works** (verified with corrected tests)

## Why Filesystem Storage Instead?

Even though NVS probably works, we chose filesystem storage for pragmatic reasons:

**Advantages of Filesystem Storage:**
- ✅ **Human-readable**: JSON files you can inspect/edit
- ✅ **Easy debugging**: `mpremote fs cat /config/controller.json`
- ✅ **Standard API**: Regular file I/O, no special knowledge needed
- ✅ **No surprises**: Well-tested, widely used
- ✅ **Already done**: Tests passing, code working

## Implementation

See `lib/config_manager.py` for the working filesystem-based implementation.

Config files are stored as:
- `/config/controller.json`
- `/config/receiver.json`

## Testing

Verified working with:
- Unit tests: `tests/test_config_manager.py` (8/8 passing)
- HWIL test: `hwil/test_config_manager_hwil.py` (persistence verified across hard reboots)

## Hard Reboot Testing Pattern

We created a reusable helper for future HWIL tests: `hwil/reboot_test_helper.py`

**Key insight**: Tests that verify persistence must NOT auto-cleanup, or you'll miss the SUCCESS message after hard reboot.

**Pattern**:
- Use a marker file (`.cleanup`) for on-demand cleanup
- Show SUCCESS message persistently
- Keep test data for inspection
- See `hwil/test_config_manager_hwil.py` for example

## Lessons Learned

1. **Auto-cleanup in HWIL tests is dangerous** - can make working code look broken
2. **Always verify assumptions** - what looks like a bug might be test methodology
3. **Filesystem storage is often better** - simpler, more debuggable than special APIs
4. **Hard reboot testing needs special care** - can't see output from automatic boot

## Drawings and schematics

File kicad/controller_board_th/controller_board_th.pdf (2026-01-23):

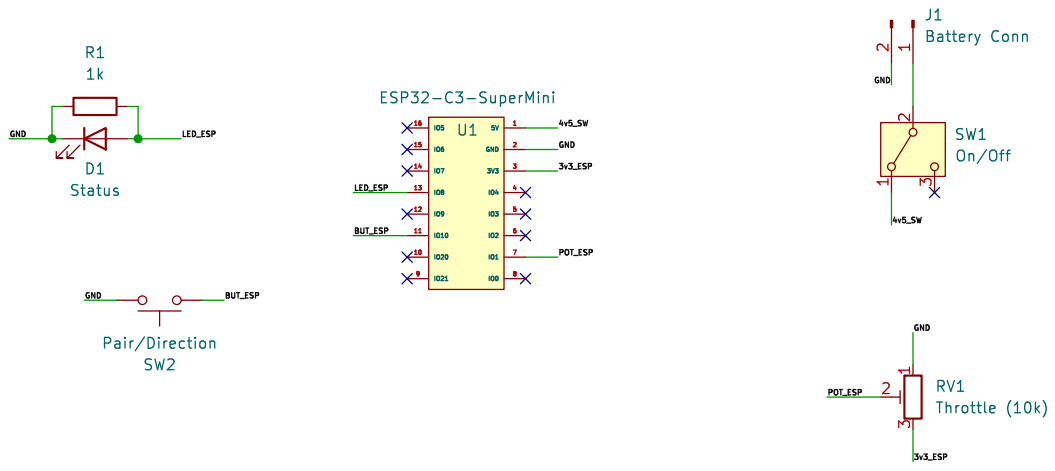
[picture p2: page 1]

Id: 1/1 Title: File: controller_board.kicad_sch Sheet: /

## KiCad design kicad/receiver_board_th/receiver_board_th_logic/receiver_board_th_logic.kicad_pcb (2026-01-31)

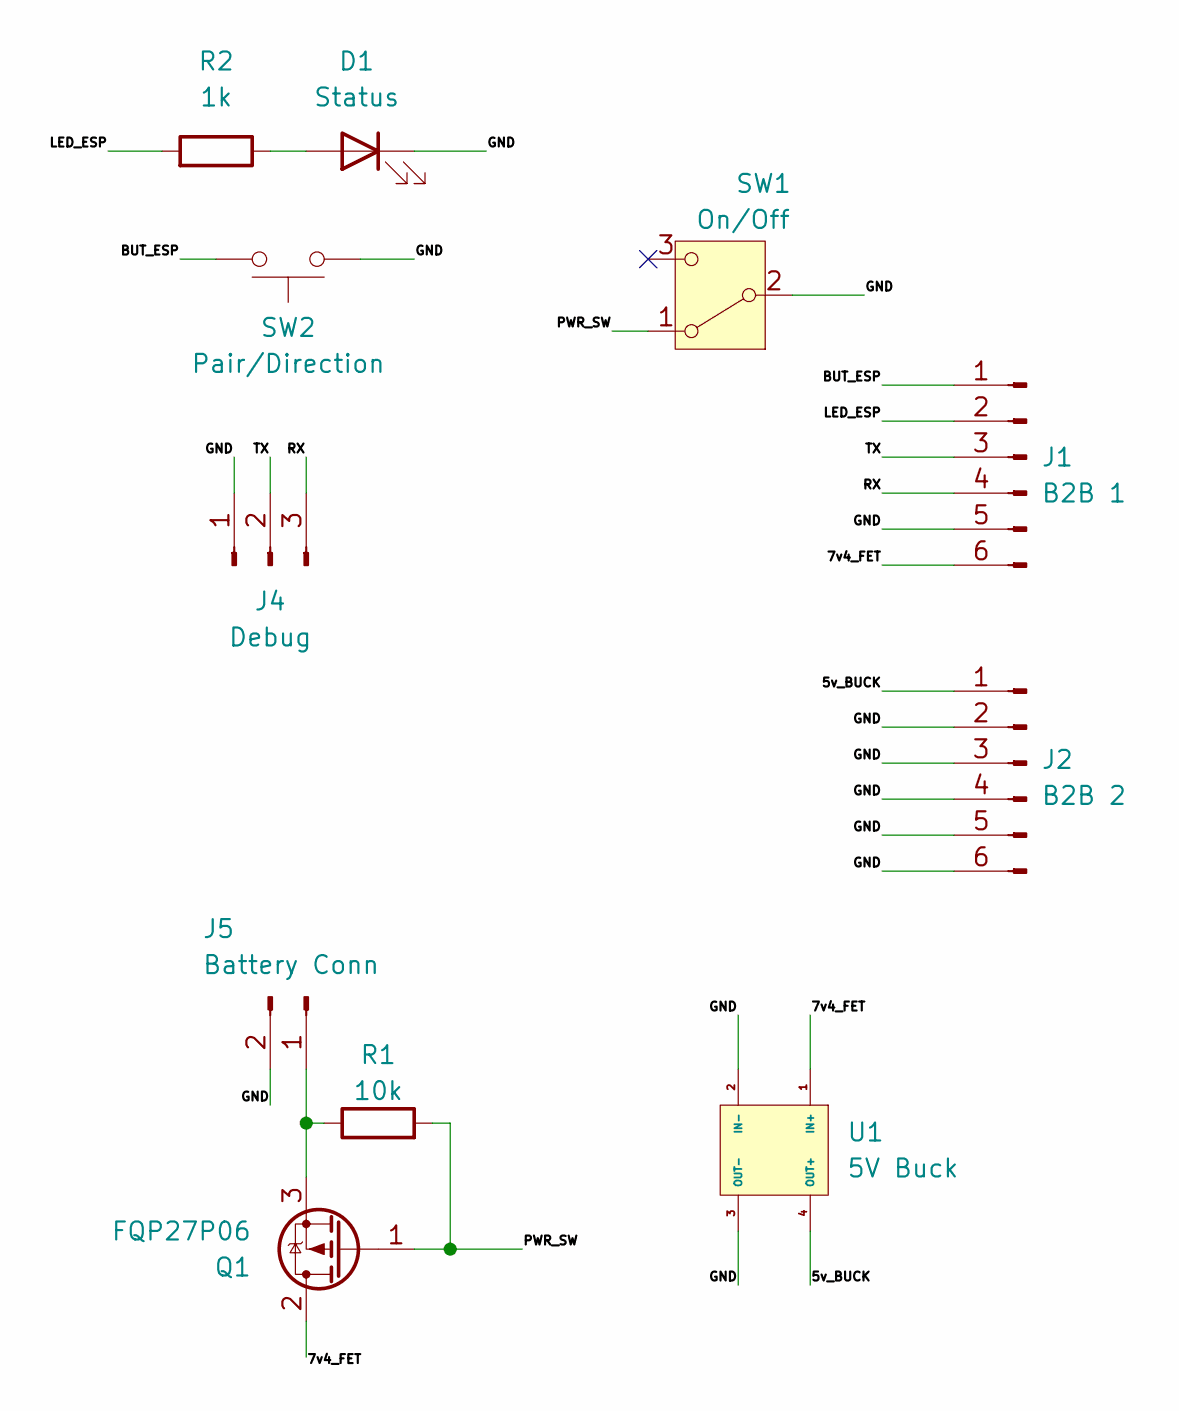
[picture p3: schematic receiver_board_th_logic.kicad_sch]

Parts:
D1: Status; LED_D5.0mm
J1: B2B 1; PinHeader_1x06_P2.54mm_Vertical
J2: B2B 2; PinHeader_1x06_P2.54mm_Vertical
J4: Debug; PinHeader_1x03_P2.54mm_Vertical
J5: Battery Conn; PinHeader_1x02_P2.54mm_Vertical
Q1: FQP27P06; TO-220-3_Vertical
R1: 10k; R_Axial_DIN0207_L6.3mm_D2.5mm_P7.62mm_Horizontal
R2: 1k; R_Axial_DIN0207_L6.3mm_D2.5mm_P7.62mm_Horizontal
SW1: On/Off; Slide_Switch_SPDT_12D00G
SW2: Pair/Direction; Push_Button_TSD016
U1: 5V Buck; MP1584EN

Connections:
/5v_BUCK: J2.1, U1.4 (OUT+)
/7v4_FET: J1.6, Q1.2 (D), U1.1 (IN+)
/BUT_ESP: J1.1, SW2.2
/GND: D1.1 (K), J1.5, J2.2, J2.3, J2.4, J2.5, J2.6, J4.1, J5.2, SW1.2 (B), SW2.1, U1.2 (IN-), U1.3 (OUT-)
/LED_ESP: J1.2, R2.2
/PWR_SW: Q1.1 (G), R1.2, SW1.1 (A)
/RX: J1.4, J4.3
/TX: J1.3, J4.2
unnamed: D1.2 (A), R2.1
unnamed: J5.1, Q1.3 (S), R1.1

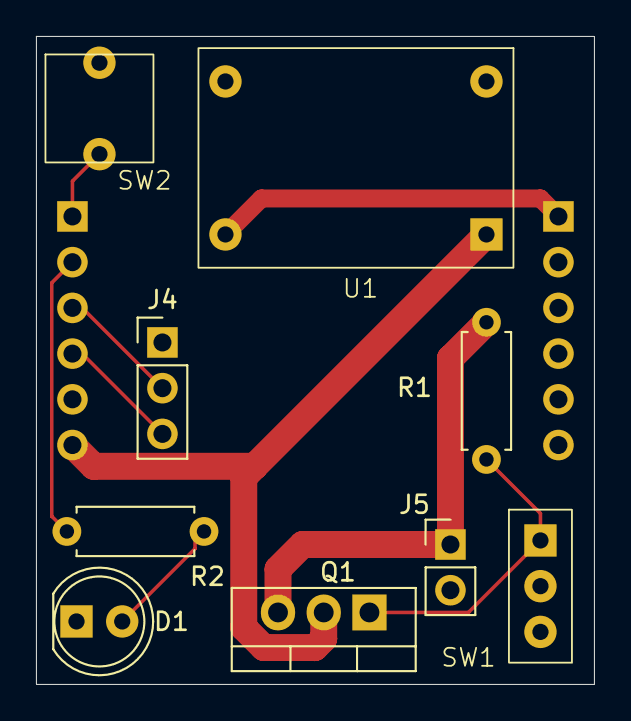
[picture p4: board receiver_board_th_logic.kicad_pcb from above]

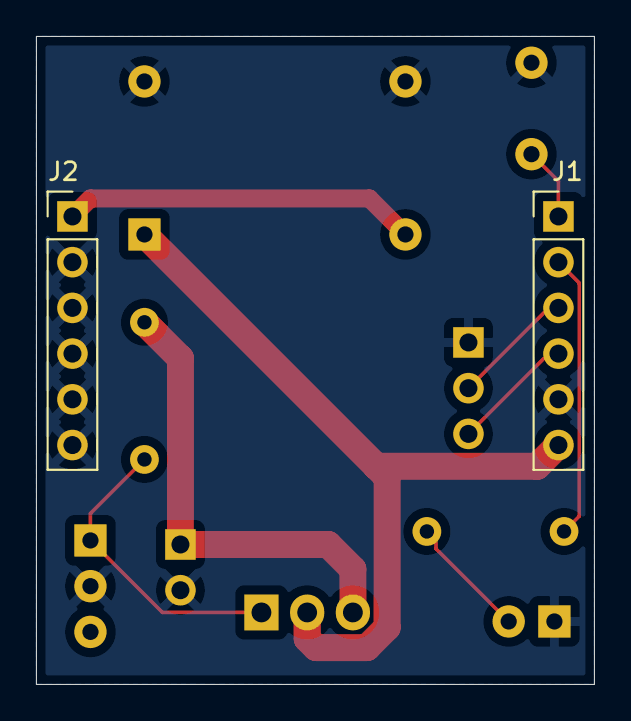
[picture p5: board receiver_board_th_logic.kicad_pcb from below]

Board: 2 copper layers, 31.0 x 36.0 mm, 11 parts (2 on the bottom side), 10 nets.

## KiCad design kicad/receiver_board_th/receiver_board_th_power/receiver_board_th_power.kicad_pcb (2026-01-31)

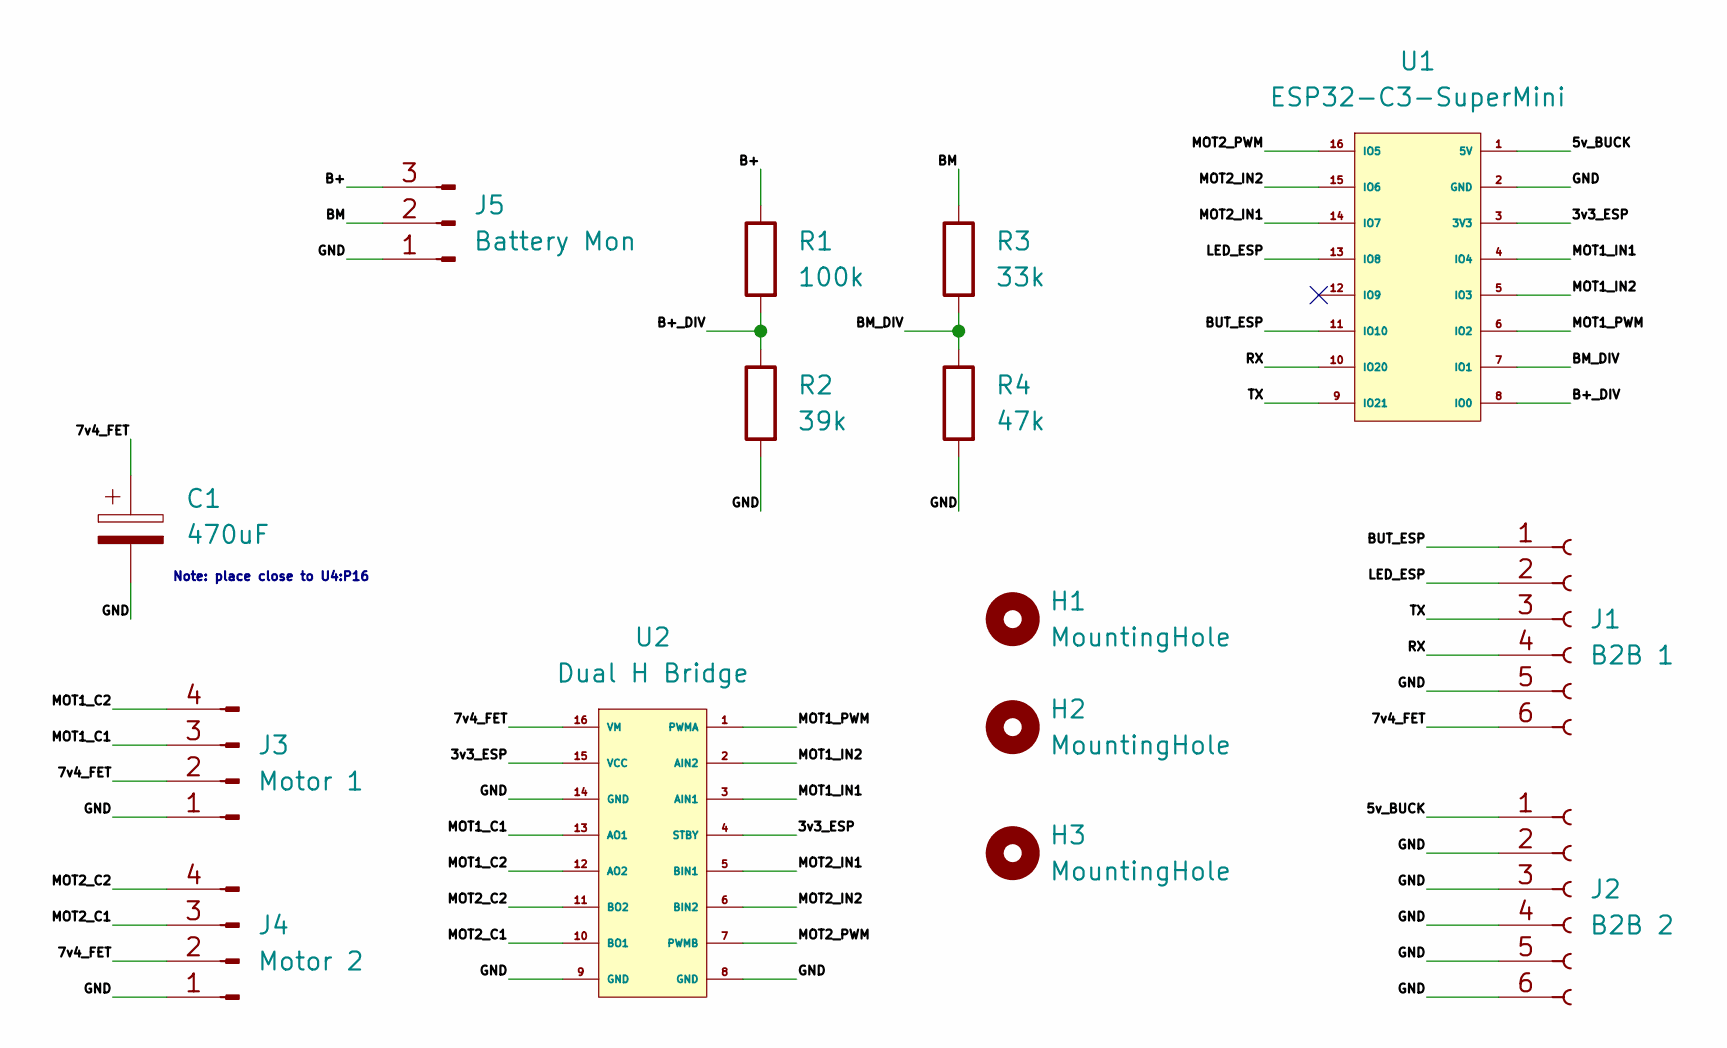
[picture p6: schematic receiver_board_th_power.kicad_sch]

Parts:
C1: 470uF; CP_Radial_D8.0mm_P5.00mm
H1, H2, H3: MountingHole; MountingHole_2.2mm_M2_Pad_TopBottom
J1: B2B 1; PinSocket_1x06_P2.54mm_Vertical
J2: B2B 2; PinSocket_1x06_P2.54mm_Vertical
J3: Motor 1; JST_XH_B4B-XH-A_1x04_P2.50mm_Vertical
J4: Motor 2; JST_XH_B4B-XH-A_1x04_P2.50mm_Vertical
J5: Battery Mon; PinHeader_1x03_P2.54mm_Vertical
R1: 100k; R_Axial_DIN0207_L6.3mm_D2.5mm_P7.62mm_Horizontal
R2: 39k; R_Axial_DIN0207_L6.3mm_D2.5mm_P7.62mm_Horizontal
R3: 33k; R_Axial_DIN0207_L6.3mm_D2.5mm_P7.62mm_Horizontal
R4: 47k; R_Axial_DIN0207_L6.3mm_D2.5mm_P7.62mm_Horizontal
U1: ESP32-C3-SuperMini
U2: Dual H Bridge; TB6612FNG

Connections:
/3v3_ESP: U1.3 (3V3), U2.4 (STBY), U2.15 (VCC)
/5v_BUCK: J2.1, U1.1 (5V)
/7v4_FET: C1.1, J1.6, J3.2, J4.2, U2.16 (VM)
/B+: J5.3, R1.1
/B+_DIV: R1.2, R2.1, U1.8 (IO0)
/BM: J5.2, R3.1
/BM_DIV: R3.2, R4.1, U1.7 (IO1)
/BUT_ESP: J1.1, U1.11 (IO10)
/GND: C1.2, J1.5, J2.2, J2.3, J2.4, J2.5, J2.6, J3.1, J4.1, J5.1, R2.2, R4.2, U1.2 (GND), U2.8 (GND), U2.9 (GND), U2.14 (GND)
/LED_ESP: J1.2, U1.13 (IO8)
/MOT1_C1: J3.3, U2.13 (AO1)
/MOT1_C2: J3.4, U2.12 (AO2)
/MOT1_IN1: U1.4 (IO4), U2.3 (AIN1)
/MOT1_IN2: U1.5 (IO3), U2.2 (AIN2)
/MOT1_PWM: U1.6 (IO2), U2.1 (PWMA)
/MOT2_C1: J4.3, U2.10 (BO1)
/MOT2_C2: J4.4, U2.11 (BO2)
/MOT2_IN1: U1.14 (IO7), U2.5 (BIN1)
/MOT2_IN2: U1.15 (IO6), U2.6 (BIN2)
/MOT2_PWM: U1.16 (IO5), U2.7 (PWMB)
/RX: J1.4, U1.10 (IO20)
/TX: J1.3, U1.9 (IO21)

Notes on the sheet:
Note: place close to U4:P16

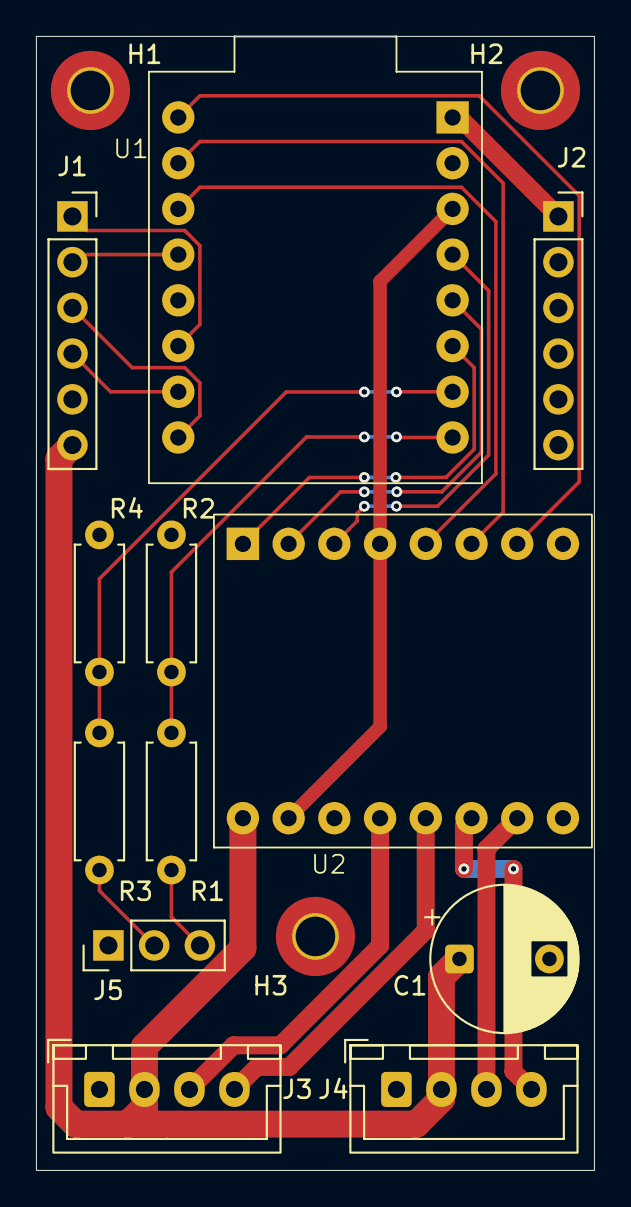
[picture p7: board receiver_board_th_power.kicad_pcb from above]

Board: 2 copper layers, 31.0 x 63.0 mm, 15 parts (0 on the bottom side), 22 nets.

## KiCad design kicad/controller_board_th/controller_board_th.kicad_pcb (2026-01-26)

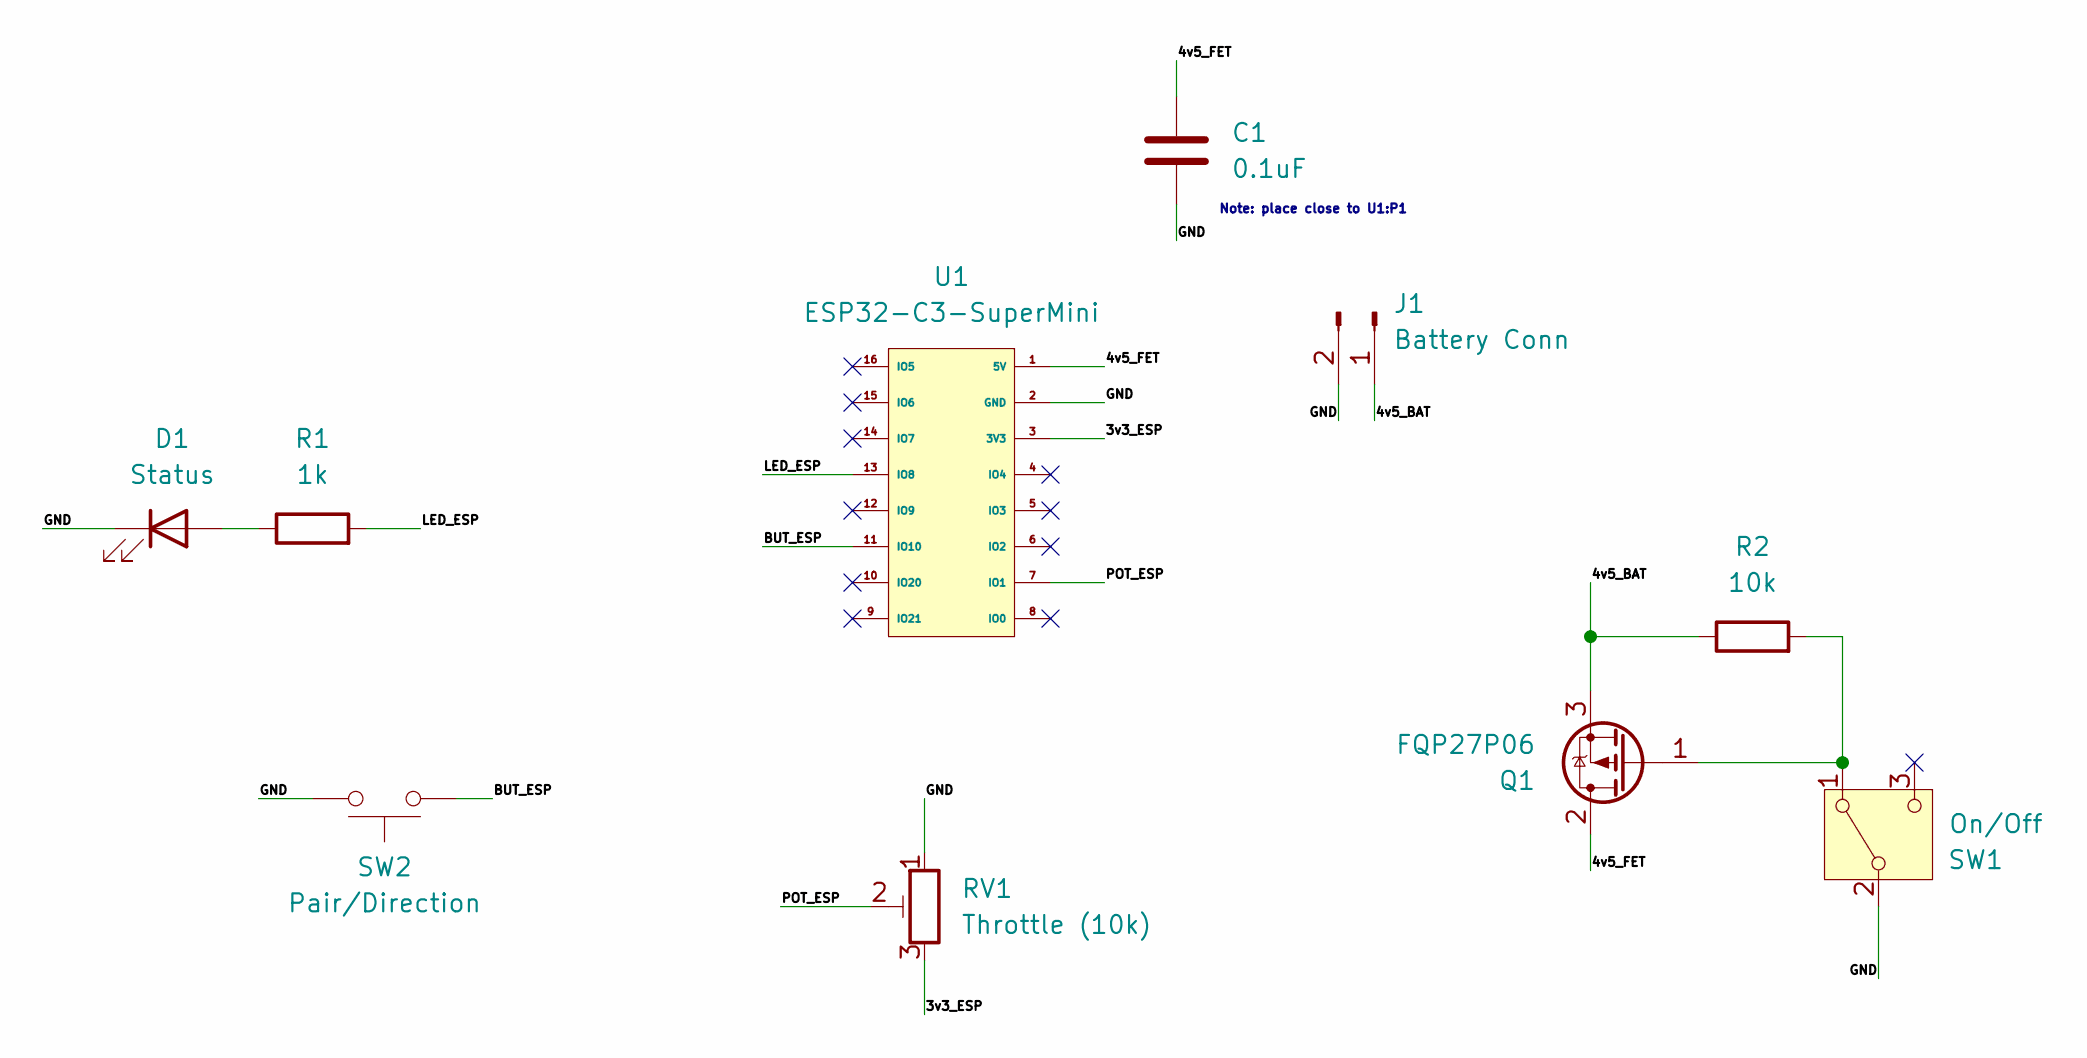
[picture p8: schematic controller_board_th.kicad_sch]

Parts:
C1: 0.1uF; C_Disc_D5.0mm_W2.5mm_P5.00mm
D1: Status; LED_D5.0mm
J1: Battery Conn; PinHeader_1x02_P2.54mm_Vertical
Q1: FQP27P06; TO-220-3_Vertical
R1: 1k; R_Axial_DIN0207_L6.3mm_D2.5mm_P7.62mm_Horizontal
R2: 10k; R_Axial_DIN0207_L6.3mm_D2.5mm_P7.62mm_Horizontal
RV1: Throttle (10k); PinSocket_1x03_P2.54mm_Vertical
SW1: On/Off; Slide_Switch_SPDT_12D00G
SW2: Pair/Direction; Push_Button_TSD016
U1: ESP32-C3-SuperMini

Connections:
/3v3_ESP: RV1.3, U1.3 (3V3)
/4v5_BAT: J1.1, Q1.3 (S), R2.1
/4v5_FET: C1.1, Q1.2 (D), U1.1 (5V)
/BUT_ESP: SW2.2, U1.11 (IO10)
/GND: C1.2, D1.1 (K), J1.2, RV1.1, SW1.2 (B), SW2.1, U1.2 (GND)
/LED_ESP: R1.2, U1.13 (IO8)
/POT_ESP: RV1.2, U1.7 (IO1)
unnamed: D1.2 (A), R1.1
unnamed: Q1.1 (G), R2.2, SW1.1 (A)

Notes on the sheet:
Note: place close to U1:P1

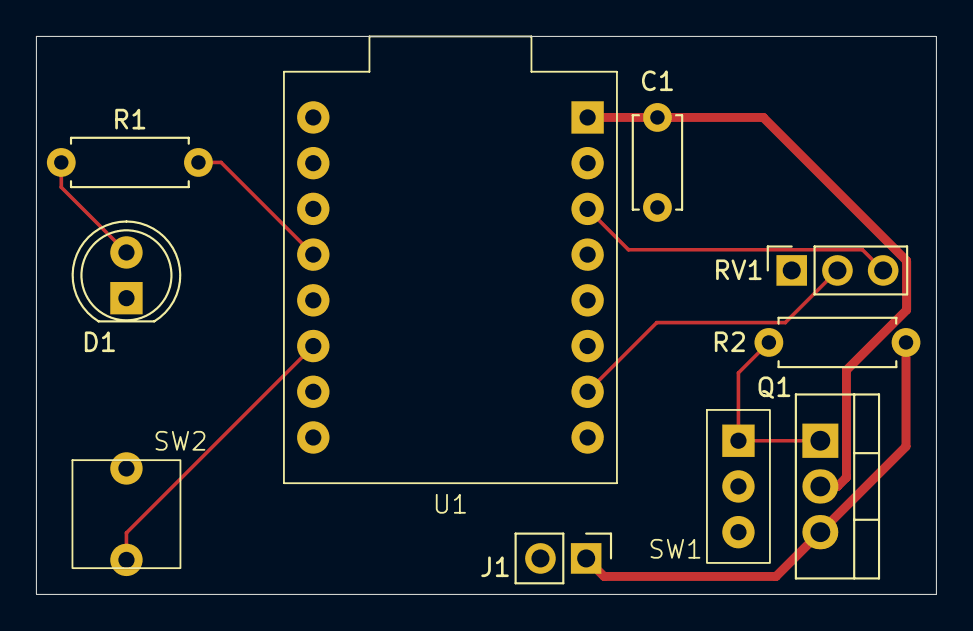
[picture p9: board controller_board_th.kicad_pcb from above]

Board: 2 copper layers, 50.0 x 31.0 mm, 10 parts (0 on the bottom side), 9 nets.

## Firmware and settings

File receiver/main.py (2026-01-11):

"""
ESP32 Lego Power Functions Receiver Application

This is the main application for the wireless receiver device that drives motors.

Hardware Setup:
    See lib/hardware.py for complete GPIO pin assignments and hardware configuration.
    - Motor 1: PWM=GPIO2, IN1=GPIO3, IN2=GPIO4
    - Motor 2: PWM=GPIO5, IN1=GPIO6, IN2=GPIO7
    - Pairing Button: GPIO10 (active low, external button)
    - Status LED: GPIO8
    - ESP-NOW: WiFi interface

Button Behavior:
    - Held during power-up: Enter pairing mode
    - Not used during normal operation

Operation:
    - Listens for ESP-NOW control messages
    - Drives motors based on received speed/direction
    - Pairing modes:
      * Button held during power-up: Waits for pairing request (proactive)
      * During normal operation: Accepts pairing if not already paired (reactive)
      * When paired: Ignores pairing requests (security)
    - LED indicates status (on=receiving, fast blink=pairing, slow blink=idle)
    - Safety timeout stops motors if no messages received
"""

import sys
import time
from machine import Pin, PWM

# Add lib to path
if '/lib' not in sys.path:
    sys.path.insert(0, '/lib')

import hardware
from button import Button
from motor_driver import MotorDriver, DualMotorDriver, MotorMode
from espnow_protocol import ESPNowProtocol, MessageType
from config_manager import ConfigManager


class ReceiverApp:
    """Main receiver application."""

    # Configuration keys
    CONFIG_PEER_MAC = 'peer_mac'

    # Safety timeout - from hardware config
    SAFETY_TIMEOUT_MS = hardware.SAFETY_TIMEOUT_MS

    # LED blink rate (Hz) - from hardware config
    PAIRING_BLINK_HZ = hardware.PAIRING_BLINK_HZ
    IDLE_BLINK_HZ = hardware.IDLE_BLINK_HZ

    # Pairing timeout - from hardware config
    PAIRING_TIMEOUT_SEC = hardware.PAIRING_TIMEOUT_SEC

    def __init__(self):
        """Initialize receiver hardware and check for pairing mode."""
        print("\n" + "="*50)
        print("ESP32 Lego Power Functions Receiver")
        print("="*50)

        # Initialize configuration manager
        self.config = ConfigManager(ConfigManager.DEVICE_RECEIVER)

        # Initialize hardware
        print("\nInitializing hardware...")

        # Pairing button (active low with pull-up)
        button_pin = Pin(hardware.BUTTON_GPIO, Pin.IN, Pin.PULL_UP)
        self.button = Button(button_pin, active_low=hardware.BUTTON_ACTIVE_LOW)

        # Load motor configuration from config manager
        motor_cfg = self.config.get('motor_config', {})
        deadband = motor_cfg.get('deadband', 0)
        reverse_m1 = motor_cfg.get('reverse_motor1', False)
        reverse_m2 = motor_cfg.get('reverse_motor2', False)
        max_speed = motor_cfg.get('max_speed', 100)

        print("Motor config: deadband={}, reverse=[{},{}], max_speed={}%".format(
            deadband, reverse_m1, reverse_m2, max_speed))

        # Motor 1 (Channel A)
        pwm1 = PWM(Pin(hardware.MOTOR1_PWM_GPIO), freq=hardware.MOTOR_PWM_FREQ, duty=0)
        in1_1 = Pin(hardware.MOTOR1_IN1_GPIO, Pin.OUT)
        in2_1 = Pin(hardware.MOTOR1_IN2_GPIO, Pin.OUT)
        motor1 = MotorDriver(pwm1, in1_1, in2_1,
                             reverse=reverse_m1,
                             deadband=deadband,
                             max_speed=max_speed)

        # Motor 2 (Channel B)
        pwm2 = PWM(Pin(hardware.MOTOR2_PWM_GPIO), freq=hardware.MOTOR_PWM_FREQ, duty=0)
        in1_2 = Pin(hardware.MOTOR2_IN1_GPIO, Pin.OUT)
        in2_2 = Pin(hardware.MOTOR2_IN2_GPIO, Pin.OUT)
        motor2 = MotorDriver(pwm2, in1_2, in2_2,
                             reverse=reverse_m2,
                             deadband=deadband,
                             max_speed=max_speed)

        # Dual motor controller
        self.motors = DualMotorDriver(motor1, motor2)

        # Status LED
        self.led = Pin(hardware.LED_GPIO, Pin.OUT)
        self.led.value(0)  # Start off

        # ESP-NOW protocol
        self.protocol = ESPNowProtocol('receiver')
        self.protocol.init()

        print("My MAC address:", self.protocol.get_mac_address_str())

        # Control state
        self.last_message_time = time.ticks_ms()
        self.active = False  # Receiving messages
        self.paired = False
        self.peer_mac = None
        self.pairing_mode = False

        # Check if button is held during power-up for pairing mode
        # Wait for debounce period, then call update() to read debounced state
        time.sleep_ms(60)  # Wait longer than 50ms debounce time
        self.button.update()  # Now debounced state will be set if button is still pressed

        if self.button.is_pressed():
            print("\n*** BUTTON HELD - ENTERING PAIRING MODE ***")
            time.sleep_ms(100)  # Brief delay to confirm
            self.button.update()
            if self.button.is_pressed():  # Double-check
                self.pairing_mode = True
                self.enter_pairing_mode()
            else:
                print("Button released too quickly, continuing to normal mode")

        # Load paired peer from config if not in pairing mode
        if not self.pairing_mode:
            self.load_paired_peer()

        print("\nReceiver initialized")
        print("Paired:", "YES" if self.paired else "NO")
        if self.paired:
            print("Peer MAC:", ':'.join(['{:02X}'.format(b) for b in self.peer_mac]))

        # Start with motors stopped
        self.motors.stop_both(brake=True)

        print("\nReady to receive")

    def load_paired_peer(self):
        """Load paired peer MAC from configuration."""
        peer_mac_str = self.config.get(self.CONFIG_PEER_MAC)

        if peer_mac_str:
            try:
                # Convert string to bytes
                self.peer_mac = bytes.fromhex(peer_mac_str.replace(':', ''))
                self.protocol.add_peer(self.peer_mac)
                self.paired = True
                print("Loaded paired peer from config:", peer_mac_str)
            except Exception as e:
                print("Error loading peer MAC:", e)
                self.paired = False
        else:
            print("No paired peer in configuration")
            self.paired = False

    def enter_pairing_mode(self):
        """
        Enter pairing mode - wait for PAIR_REQUEST and respond.

        LED blinks fast while waiting for pairing.
        """
        print("\n" + "="*50)
        print("PAIRING MODE")
        print("="*50)
        print("\nWaiting for pairing request from controller...")
        print("Timeout: {} seconds\n".format(self.PAIRING_TIMEOUT_SEC))

        # Wait for PAIR_REQUEST with LED blinking
        start_time = time.time()
        led_state = False
        last_blink = time.time()
        blink_period = 1.0 / self.PAIRING_BLINK_HZ / 2  # Half period for toggle

        while time.time() - start_time < self.PAIRING_TIMEOUT_SEC:
            # Blink LED
            if time.time() - last_blink > blink_period:
                led_state = not led_state
                self.led.value(led_state)
                last_blink = time.time()

            # Check for PAIR_REQUEST
            msg = self.protocol.receive(timeout_ms=100)
            if msg and msg['type'] == MessageType.PAIR_REQUEST:
                self.handle_pairing_request(msg['sender_mac'])
                return

        # Timeout
        print("\n*** PAIRING TIMEOUT ***")
        print("No controller paired")
        print("Device will continue in unpaired mode\n")
        self.led.value(0)  # LED off = not paired
        self.paired = False

    def handle_pairing_request(self, sender_mac):
        """
        Handle pairing request from controller.

        Args:
            sender_mac: MAC address of requesting controller
        """
        self.peer_mac = sender_mac
        peer_mac_str = ':'.join(['{:02X}'.format(b) for b in sender_mac])

        print("\n*** PAIRING REQUEST ***")
        print("From:", peer_mac_str)

        # Send acknowledgment
        self.protocol.send_pair_ack(sender_mac)
        print("Sent PAIR_ACK")

        # Add peer and save to config
        self.protocol.add_peer(self.peer_mac)
        self.config.set(self.CONFIG_PEER_MAC, peer_mac_str)
        self.config.save()  # Persist to filesystem
        self.paired = True

        print("Pairing saved to config")
        print("*** PAIRING COMPLETE ***\n")

        # LED on solid = paired
        self.led.value(1)
        time.sleep(2)  # Brief pause to show success

    def handle_control_message(self, msg):
        """
        Handle control message - drive motors.

        Args:
            msg: Decoded message dictionary with speed and direction
        """
        speed = msg['speed']
        direction = msg['direction']

        # Convert direction to MotorMode
        mode = MotorMode.FORWARD if direction == 0 else MotorMode.REVERSE

        # Drive both motors
        self.motors.drive_both(speed, mode)

        # Update state
        self.last_message_time = time.ticks_ms()
        self.active = True
        self.led.value(1)  # LED on = active

    def check_safety_timeout(self):
        """
        Check if we've exceeded safety timeout without messages.

        Stops motors if timeout exceeded.
        """
        if not self.active:
            return  # Already stopped

        elapsed = time.ticks_diff(time.ticks_ms(), self.last_message_time)

        if elapsed > self.SAFETY_TIMEOUT_MS:
            print("SAFETY TIMEOUT - stopping motors")
            self.motors.stop_both(brake=True)
            self.active = False
            # LED will blink in idle state

    def run(self):
        """
        Main receiver loop.

        Listens for messages and drives motors accordingly.
        Handles pairing requests only when not already paired (security).
        Implements safety timeout.
        """
        print("\n" + "="*50)
        print("RECEIVER RUNNING")
        print("="*50)
        print("\nListening for messages...")
        if self.paired:
            print("Paired mode - pairing requests will be ignored")
        else:
            print("Unpaired mode - will accept first pairing request")
        print("Safety timeout: {} ms".format(self.SAFETY_TIMEOUT_MS))
        print("Press Ctrl+C to stop\n")

        # LED blink state for idle
        led_blink_state = False
        last_blink_time = time.ticks_ms()
        blink_period_ms = int(1000 / self.IDLE_BLINK_HZ / 2)  # Half period for toggle

        try:
            while True:
                # Check for messages (non-blocking)
                msg = self.protocol.receive(timeout_ms=0)

                if msg:
                    if (msg['type'] == MessageType.CONTROL) and self.paired:
                        # Control message - drive motors
                        self.handle_control_message(msg)

                        # Print status every 20 messages
                        if self.protocol.rx_total % 20 == 0:
                            print("Speed: {:3d}%  Motor 1: {:4d}  Motor 2: {:4d}  Direction: {}  Messages received: {}".format(
                                msg['speed'],
                                self.motors.motor1.get_pwm(),
                                self.motors.motor2.get_pwm(),
                                "FWD" if msg['direction'] == 0 else "REV",
                                self.protocol.rx_total
                            ))

                    elif msg['type'] == MessageType.PAIR_REQUEST:
                        # Pairing request - only accept if not already paired (security)
                        if not self.paired:
                            self.handle_pairing_request(msg['sender_mac'])
                        else:
                            # Already paired - ignore pairing requests
                            print("WARNING: Ignoring pairing request (already paired)")

                    elif msg['type'] == MessageType.PING:
                        # Ping request - respond with pong
                        if self.peer_mac != msg['sender_mac']:
                            self.protocol.add_peer(msg['sender_mac'])
                        self.protocol.send_pong()

                # Check safety timeout
                self.check_safety_timeout()

                # Update LED blinking when idle
                if not self.active:
                    if time.ticks_diff(time.ticks_ms(), last_blink_time) > blink_period_ms:
                        led_blink_state = not led_blink_state
                        self.led.value(led_blink_state)
                        last_blink_time = time.ticks_ms()

                # Small delay to avoid busy-waiting
                time.sleep_ms(1)

        except KeyboardInterrupt:
            print("\n\nReceiver stopped")
            print("Total messages received:", self.protocol.rx_total)

        finally:
            # Cleanup
            print("Shutting down...")
            self.motors.stop_both(brake=True)
            self.led.value(0)
            self.protocol.deinit()
            print("Motors stopped")
            print("Goodbye!")


# Create and run receiver
if __name__ == "__main__":
    time.sleep_ms(3000) # Delay to allow serial monitor to connect
    receiver = ReceiverApp()
    receiver.run()

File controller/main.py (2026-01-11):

"""
ESP32 Lego Power Functions Controller Application

This is the main application for the wireless controller device.

Hardware Setup:
    See lib/hardware.py for complete GPIO pin assignments and hardware configuration.
    - Button: GPIO10 (active low, internal pull-up)
    - Potentiometer: GPIO1 (ADC)
    - Status LED: GPIO8
    - ESP-NOW: WiFi interface

Button Behavior:
    - Held during power-up: Enter pairing mode
    - Press during operation: Toggle direction (forward/reverse)

Operation:
    - Potentiometer controls speed (0-100%)
    - Button toggles direction
    - Sends control messages at 20Hz to paired receiver
    - LED indicates status (on=paired, blink=pairing, off=error)
"""

import sys
import time
from machine import Pin, ADC

# Add lib to path
if '/lib' not in sys.path:
    sys.path.insert(0, '/lib')

from button import Button
from potentiometer import Potentiometer
from espnow_protocol import ESPNowProtocol, MessageType
from config_manager import ConfigManager
import hardware


class ControllerApp:
    """Main controller application."""

    # Configuration keys
    CONFIG_PEER_MAC = 'peer_mac'

    # Control loop rate (Hz) - from hardware config
    CONTROL_RATE_HZ = hardware.TX_RATE_HZ
    CONTROL_PERIOD_MS = hardware.TX_PERIOD_MS

    # Pairing timeout
    PAIRING_TIMEOUT_SEC = 30

    def __init__(self):
        """Initialize controller hardware and check for pairing mode."""
        print("\n" + "="*50)
        print("ESP32 Lego Power Functions Controller")
        print("="*50)

        # Initialize configuration manager
        self.config = ConfigManager(ConfigManager.DEVICE_CONTROLLER)

        # Initialize hardware
        print("\nInitializing hardware...")

        # Button (active low with pull-up)
        button_pin = Pin(hardware.BUTTON_GPIO, Pin.IN, Pin.PULL_UP)
        self.button = Button(button_pin, active_low=hardware.BUTTON_ACTIVE_LOW)

        # Potentiometer (ADC)
        adc = ADC(Pin(hardware.POT_GPIO))
        adc.atten(ADC.ATTN_11DB)  # Full 0-3.3V range
        self.pot = Potentiometer(adc)

        # Status LED
        self.led = Pin(hardware.LED_GPIO, Pin.OUT)
        self.led.value(0)  # Start off

        # ESP-NOW protocol
        self.protocol = ESPNowProtocol('controller')
        self.protocol.init()

        print("My MAC address:", self.protocol.get_mac_address_str())

        # Control state
        self.speed = 0
        self.direction = 0  # 0=forward, 1=reverse
        self.paired = False
        self.peer_mac = None

        # Check if button is held during power-up for pairing mode
        # Wait for debounce period, then call update() to read debounced state
        time.sleep_ms(60)  # Wait longer than 50ms debounce time
        self.button.update()  # Now debounced state will be set if button is still pressed

        if self.button.is_pressed():
            print("\n*** BUTTON HELD - ENTERING PAIRING MODE ***")
            time.sleep_ms(100)  # Brief delay to confirm
            self.button.update()
            if self.button.is_pressed():  # Double-check
                self.enter_pairing_mode()
            else:
                print("Button released too quickly, continuing to normal mode")

        # Load paired peer from config if not in pairing mode
        if not self.paired:
            self.load_paired_peer()

        print("\nController initialized")
        print("Paired:", "YES" if self.paired else "NO")
        if self.paired:
            print("Peer MAC:", ':'.join(['{:02X}'.format(b) for b in self.peer_mac]))
            self.led.value(1)  # LED on = paired
        else:
            print("\nWARNING: No paired receiver!")
            print("Hold button during power-up to enter pairing mode")
            self.led.value(0)  # LED off = not paired

    def load_paired_peer(self):
        """Load paired peer MAC from configuration."""
        peer_mac_str = self.config.get(self.CONFIG_PEER_MAC)

        if peer_mac_str:
            try:
                # Convert string to bytes
                self.peer_mac = bytes.fromhex(peer_mac_str.replace(':', ''))
                self.protocol.add_peer(self.peer_mac)
                self.paired = True
                print("Loaded paired peer from config:", peer_mac_str)
            except Exception as e:
                print("Error loading peer MAC:", e)
                self.paired = False
        else:
            print("No paired peer in configuration")
            self.paired = False

    def enter_pairing_mode(self):
        """
        Enter pairing mode - send broadcast PAIR_REQUEST and wait for PAIR_ACK.

        LED blinks while waiting for pairing.
        """
        print("\n" + "="*50)
        print("PAIRING MODE")
        print("="*50)
        print("\nSending pairing request...")
        print("Make sure receiver is powered on and ready")
        print("Timeout: {} seconds\n".format(self.PAIRING_TIMEOUT_SEC))

        # Send pairing request
        self.protocol.send_pair_request()

        # Wait for PAIR_ACK with LED blinking
        start_time = time.time()
        led_state = False
        last_blink = time.time()

        while time.time() - start_time < self.PAIRING_TIMEOUT_SEC:
            # Blink LED at 2Hz
            if time.time() - last_blink > 0.25:
                led_state = not led_state
                self.led.value(led_state)
                last_blink = time.time()

            # Check for PAIR_ACK
            msg = self.protocol.receive(timeout_ms=100)
            if msg and msg['type'] == MessageType.PAIR_ACK:
                # Got pairing acknowledgment
                self.peer_mac = msg['sender_mac']
                peer_mac_str = ':'.join(['{:02X}'.format(b) for b in self.peer_mac])

                print("\n*** PAIRING SUCCESS ***")
                print("Paired with:", peer_mac_str)

                # Add peer and save to config
                self.protocol.add_peer(self.peer_mac)
                self.config.set(self.CONFIG_PEER_MAC, peer_mac_str)
                self.config.save()  # Persist to filesystem
                self.paired = True

                print("Pairing saved to config")

                # LED on solid = paired
                self.led.value(1)

                print("\nPairing complete!")
                time.sleep(2)  # Brief pause to show success
                return

            # Resend pairing request every 2 seconds
            if int(time.time() - start_time) % 2 == 0:
                self.protocol.send_pair_request()
                time.sleep_ms(100)  # Avoid spamming

        # Timeout
        print("\n*** PAIRING TIMEOUT ***")
        print("No receiver responded")
        print("Please try again\n")
        self.led.value(0)  # LED off = failed
        self.paired = False

    def run(self):
        """
        Main control loop.
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

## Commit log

2025-12-30 Implement Phase 1 Step 1: ConfigManager with filesystem storage
    Add persistent configuration management for ESP32 controller/receiver devices:
    - Filesystem-based JSON storage in /config directory
    - Configuration versioning and migration support
    - Dot-notation for nested configuration keys
    - Separate defaults for controller and receiver device types
    - 8 unit tests verifying save/load, persistence, and nested keys
    - HWIL test with marker file cleanup pattern for hard reboot verification
    - Deployment scripts and comprehensive documentation
    Naming conventions:
    - Unit tests: tests/test_<module>.py
    - HWIL tests: hwil/test_<module>_hwil.py
    Documentation includes lessons learned from NVS testing m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
    [reboot_test_helper.py, test_config_manager_hwil.py]
2025-12-31 Implement Phase 1 Step 2: Button module with debouncing
    Add debounced button input handling with edge detection and long press
    support for controller direction button and receiver pairing button.
    Features:
    - Configurable debounce timing (default 50ms)
    - Edge detection (was_pressed/was_released)
    - Press duration tracking for pairing mode
    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
2025-12-31 Implement Phase 1 Step 3: LED pattern control module
    Add pattern-based LED control for status indication on controller
    (forward/reverse mode and pairing status).
    - Five patterns: SOLID_OFF, SOLID_ON, BLINK_SLOW, BLINK_FAST, BLINK_VERY_FAST
    - Configurable timing (500ms/100ms/50ms blink rates)
    - Active-high and active-low support
    - Polling-based update system (matches button module design)
    - Convenience methods: turn_on(), turn_off()
    - MicroPython/CPython compatibility for unit testing
    All unit tests passing (12/12) and hardware validated on ESP32-C3.
    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
    [test_led_hwil.py]
2025-12-31 Implement Phase 1 Step 4: Potentiometer ADC module with calibration
    Add ADC-based potentiometer reader for controller speed input with
    dead zone support for clean motor stop at minimum position.
    - Reads analog input and maps to speed percentage (0-100)
    - Configurable calibration (min_val, max_val, zero_band)
    - Dead zone at minimum prevents jitter near zero speed
    - Input validation for calibration parameters
    - Raw ADC access for debugging and calibration
    Hardware-in-loop tests include:
    - Continuous read with live bar graph display
    - Calibration helper to auto-detect min/max values
    - Zero band behavior visualization
    - Custom calibration validation
    All unit tests passing (15/15) an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
    [test_potentiometer.py, test_potentiometer_hwil.py]
2026-01-01 Implement Phase 1 Step 5: TB6612 motor driver module
    Add motor driver control for TB6612FNG dual H-bridge to drive two
    DC motors (Lego Power Functions) with PWM speed control.
    - Single motor control (MotorDriver class)
    - Dual motor control (DualMotorDriver class)
    - Four operation modes: FORWARD, REVERSE, BRAKE, COAST
    - PWM speed control (0-100%)
    - Configurable motor reversal for wiring corrections
    - Deadband support to ignore low speeds
    - Safety default: initializes to BRAKE mode
    - Single motor test through all modes
    - Speed ramping (0-100%)
    - Dual motor coordinated and independent control
    - Motor direction reversal testing
    - Interactive REPL contr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
    [test_motor_driver.py, test_motor_driver_hwil.py]
2026-01-03 Implement Phase 2: ESP-NOW communication protocol
    Add wireless communication layer using ESP-NOW for low-latency
    controller-receiver link (target <10ms latency).
    - Compact 4-byte message protocol (type, sequence, speed, direction)
    - Five message types: CONTROL, PING, PONG, PAIR_REQUEST, PAIR_ACK
    - Automatic sequence numbering with wraparound at 255
    - Peer management (add/remove by MAC address)
    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
2026-01-03 Fix ESP-NOW pairing and improve debug output
    ESP-NOW fixes:
    - Add broadcast peer (FF:FF:FF:FF:FF:FF) during init for pairing
    - Implement _peer_exists() using get_peers() to avoid duplicate adds
    - Prevents ESP_ERR_ESPNOW_NOT_FOUND when broadcasting pairing requests
    HWIL test improvements:
    - Print sequence number for each message sent/received
    - Reduce transmit rate to 2Hz (500ms) for easier debugging
    - Show per-message details instead of aggregated stats
    - Highlight missed messages with sequence gap detection
    - Cleaner output for validating message integrity
    Hardware validation: Pairing working, messages match on both sides.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
    [test_espnow_protocol_hwil.py]
2026-01-04 Separate 8-bit sequence from message totals in ESP-NOW protocol
    Add tx_total and rx_total counters for lifetime message statistics,
    separate from the 8-bit protocol sequence number that wraps at 256.
    Changes:
    - Add tx_total/rx_total fields to ESPNowProtocol (unbounded counters)
    - Centralize sequence increment in _send() to avoid duplication
    - Add BROADCAST_MAC constant to avoid hardcoded broadcast address
    - Update add_peer() to not set peer_mac for broadcast address
    - Add 5 new unit tests for counter behavior (19/19 passing)
    - Update HWIL tests to display both sequence and tx/rx totals
    This separation makes it clear that:
    - sequence: 8-bit protocol field (0-255, wraps)
    - tx_total/rx_total: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
    [test_espnow_protocol_hwil.py]
2026-01-04 Add ESP-NOW API performance timing to HWIL tests
    Measure send_control() and receive() performance to determine if
    threading is needed for main application loop.
    - Add microsecond timing to test_sender() for send operations
    - Add microsecond timing to test_receiver() for receive operations
    - Use timeout_ms=0 in receiver for accurate non-blocking timing
    - Display timing in real-time output and final statistics
    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
2026-01-05 Add controller and receiver main applications (UNTESTED)
    Controller features:
    - Button held during power-up: Enter pairing mode
    - Button press during operation: Toggle direction
    - Potentiometer controls speed (0-100%)
    - 20Hz control message transmission
    - Persistent pairing via ConfigManager
    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
2026-01-05 Update README: Motor driver hardware validated
    Phase 1 (Foundation Modules) is now complete - all modules hardware tested:
    - ConfigManager: NVM storage working
    - Button: Debouncing validated
    - LED: Pattern control working
    - Potentiometer: Dead zone calibration tested
    - Motor driver: TB6612 PWM control validated on hardware
    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
2026-01-09 Add pairing button and security to receiver application
    Security improvements:
    - Button on GPIO9 required during power-up for proactive pairing mode
    - During normal operation, only accepts pairing if not already paired
    - Once paired, ignores all pairing requests (prevents unauthorized re-pairing)
    Pairing modes:
    - Proactive: Button held during power-up waits for pairing request (30s timeout)
    - Reactive: During normal operation accepts first pairing request if unpaired
    - Secured: When paired, all pairing requests are rejected
    LED indicators:
    - Fast blink (4Hz): Pairing mode
    - Slow blink (1Hz): Idle/unpaired
    - Solid on: Receiving control messages
    This prevents the security issue where any ne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
    [main.py]
2026-01-09 Reorganize GPIO assignments for cleaner wiring
    Controller (unchanged):
    - Potentiometer: GPIO1 (ADC)
    - LED: GPIO8
    - Button: GPIO10
    Receiver (improved):
    - Motor 1: GPIO2 (PWM), GPIO3 (IN1), GPIO4 (IN2) - sequential
    - Motor 2: GPIO5 (PWM), GPIO6 (IN1), GPIO7 (IN2) - sequential
    - LED: GPIO8 (matches controller)
    - Button: GPIO10 (matches controller, avoids GPIO9/BOOT conflict)
    Benefits:
    - Avoids GPIO9 (BOOT) which enters bootloader when held during power-up
    - Sequential motor pins (2-3-4 and 5-6-7) for clean breadboard wiring
    - Consistent LED and button pins across both devices
    - Each motor is a clean 3-wire bundle for easier troubleshooting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
    [main.py, test_motor_driver_hwil.py]
2026-01-10 Fix ConfigManager initialization in controller and receiver apps
    Added DEVICE_CONTROLLER and DEVICE_RECEIVER constants to ConfigManager class.
    Bug fix: Controller and receiver apps were calling ConfigManager() without
    the required device_type parameter, causing TypeError during initialization.
    - lib/config_manager.py: Add DEVICE_CONTROLLER and DEVICE_RECEIVER constants
    - controller/main.py: Pass ConfigManager.DEVICE_CONTROLLER to ConfigManager()
    - receiver/main.py: Pass ConfigManager.DEVICE_RECEIVER to ConfigManager()
    - hwil/test_config_manager_hwil.py: Use constant instead of hardcoded string
    - tests/test_config_manager.py: Use constants in all test cases
    This ensures each devic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
    [main.py, test_config_manager_hwil.py]
2026-01-10 Fix button detection during power-up for pairing mode
    Bug fix: Button presses during power-up were not being detected because
    is_pressed() was checked before the debounced state was updated.
    Root cause: The Button class requires the debounce period (50ms default)
    to elapse BEFORE calling update() to set the debounced state. Previous
    code called update() multiple times but never waited the full debounce
    period first.
    Solution: Wait 60ms (longer than 50ms debounce time), THEN call update()
    once. This ensures:
    - Button state has been stable for >50ms
    - update() will recognize the stable state and set _state = True
    - is_pressed() will correctly return True
    - controller/main.py: Wait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
    [main.py]
2026-01-10 Fix incorrect method call in controller main loop
    Bug fix: Controller was calling pot.read_percent() which doesn't exist.
    The correct method name is pot.read() (returns 0-100).
    - controller/main.py:229: read_percent() → read()
    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
    [main.py]
2026-01-10 Fix button direction toggle triggering repeatedly while held
    Bug fix: Direction was toggling continuously while button was held down
    instead of toggling only once per press.
    Root cause: Using is_pressed() which returns True continuously while held,
    instead of was_pressed() which is an edge detector that only triggers once
    on the press event.
    - controller/main.py:224: is_pressed() → was_pressed()
    The was_pressed() method uses edge detection - it returns True only once
    when the button transitions from released to pressed, then automatically
    clears the flag. This is the correct behavior for toggle actions.
    Co-Auth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
    [main.py]
2026-01-10 Mark Phase 3 complete - end-to-end system validation successful
    Updated development phase status:
    - Phase 3: Application Logic - COMPLETE ✅
    * Controller and receiver apps fully functional
    * End-to-end hardware validation successful
    * Pairing, wireless control, and motor operation all working
    - Phase 4: Configuration & Deployment
    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
2026-01-10 Fix config persistence - add missing save() calls after pairing
    Both controller and receiver were calling config.set() to update pairing
    information but never calling config.save() to persist to filesystem.
    This caused pairing to be lost on every reboot.
    [main.py]
2026-01-10 Add raw ADC value to controller status output
    Display raw potentiometer ADC count alongside calibrated percentage
    for easier debugging and calibration tuning.
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2026-01-10 Fix GPIO mappings in all HWIL tests to match official IO assignments
    Critical fixes to ensure HWIL tests work on actual hardware:
    - test_button_hwil.py: GPIO1/9 → GPIO10 (both controller & receiver)
    - test_led_hwil.py: GPIO2 → GPIO8 (status LED)
    - test_potentiometer_hwil.py: GPIO0 → GPIO1 (ADC input)
    - test_motor_driver_hwil.py: Motor2 pins fixed in test_interactive()
    - PWM: GPIO4 → GPIO5
    - IN1: GPIO5 → GPIO6
    - IN2: GPIO6 → GPIO7
    All changes verified against README.md GPIO assignments table.
    Added comprehensive HWIL_AUDIT_REPORT.md documenting the audit
    process, issues found, API coverage analysis, and recommendations.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
    [test_button_hwil.py, test_led_hwil.py, test_motor_driver_hwil.py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]
2026-01-11 Fix all README files with correct GPIO mappings and tool references
    Critical documentation fixes to prevent hardware wiring errors:
    Controller/Receiver GPIO Updates:
    - controller/README.md: Fixed all GPIO pins (0→1, 1→10, 2→8)
    - receiver/README.md: Fixed motor driver pins and added complete TB6612 mapping
    - Both: Added power supply warnings and hardware notes
    Tool & Test Documentation:
    - hwil/README.md: Changed ampy→mpremote, fixed test file names
    - tests/README.md: Added all 6 test files (was only showing 3)
    - tools/README.md: Fixed script names (flash_*→deploy_*), removed ampy
    - lib/README.md: Updated NVM→filesystem storage terminology
    Added comprehensive README_AUDIT_REPORT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
2026-01-11 Implement interactive CLI for device configuration (tools/cli.py)
    - Auto-detects device type (controller/receiver) from config files
    - Interactive REPL with readline support for command history
    - Config commands: show(), get(), set(), unpair(), save(), reset(), erase()
    - Supports dot notation for nested keys (e.g., 'pot_calibration.min')
    - Auto-saves on set() to persist changes immediately
    - Device-aware unpair() clears correct MAC field per device type
    - MicroPython-compatible JSON handling (formats on host side)
    - Comprehensive error handling and help system
    Usage: python tools/cli.py COM3
    Updated tools/README.md to reflect CLI is now implemented.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
2026-01-11 Add max_speed feature and fix motor_config usage (v1→v2 migration)
    New Feature: Motor Speed Limiting
    - Add configurable max_speed parameter (0-100%) to motor_config
    - Scales motor PWM output for battery life/safety/power management
    - Single max_speed value applies to both motors (default: 100%)
    - Configurable via CLI: config.set('motor_config.max_speed', 50)
    Implementation:
    - lib/motor_driver.py:
    * Add max_speed parameter to __init__ (default: 100)
    * Add set_max_speed() method with 0-100 validation
    * Update drive() to apply max_speed scaling before deadband
    * Scaling order: clamp → max_speed → deadband → PWM
    - lib/config_manager.py:
    * Increment VERSION from 1 to 2
    * Add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
    [main.py, test_motor_driver.py]
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2026-01-23 Add complete KiCad schematics for controller and receiver boards
    Implement P-channel MOSFET high-side power switching on both boards
    to handle load requirements (receiver: 2A+ motor current, controller:
    300mA max). Previous design used direct SPDT switching insufficient
    for receiver motor loads.
    Controller schematic:
    - ESP32-C3-SuperMini with 2xAA battery power (3V-4.5V)
    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
    [controller_board.kicad_pcb, controller_board.kicad_sch, receiver_board.kicad_pcb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]
2026-01-23 Split receiver into two-board design for PF battery box fit
    Divide receiver into upper and lower PCBs to meet physical constraints
    of Lego Power Functions 8x4 stud battery box housing.
    Lower board (receiver_board_lower):
    - 2S BMS with USB-C charging
    - MP1584EN buck converter (8.4V → 5V)
    - FQP27P06 P-FET power switching
    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
    [receiver_board_lower.kicad_pcb, receiver_board_lower.kicad_sch, receiver_board_upper.kicad_pcb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]
2026-01-23 Finished generating footprints for all parts. Receiver boards layout and stacking order is still TBD, so renamed them from "uppper" and "lower" to "power" and "logic" as that will likely be the rough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
    [receiver_board_logic.kicad_pcb, receiver_board_logic.kicad_sch, receiver_board_power.kicad_pcb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]
2026-01-24 Update GPIO assignments and complete first-pass PCB layout
    Swap motor control IN1/IN2 pins to simplify PCB routing:
    - Motor 1: IN1 GPIO4, IN2 GPIO3 (was IN1 GPIO3, IN2 GPIO4)
    - Motor 2: IN1 GPIO7, IN2 GPIO6 (was IN1 GPIO6, IN2 GPIO7)
    Updated documentation:
    - lib/hardware.py: Motor GPIO pin definitions
    - README.md: Receiver GPIO assignment table
    - receiver/README.md: Hardware pin descriptions
    PCB design progress:
    - Controller board: First-pass layout and routing complete
    - Receiver logic board: First-pass layout and routing complete
    - Receiver power board: First-pass layout and routing complete
    - All decoupling capacitors added (470µF on TB6612 VM, 0.1µF on logic)
    - Verified netlists: pow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
    [controller_board.kicad_pcb, controller_board.kicad_sch, receiver_board_logic.kicad_pcb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]
2026-01-25 Add battery monitor connector and update receiver power board layout
    - Add 3-pin battery monitor connector (J3) to receiver power board
    - Connected to BMS balance leads (B+, BM, B-)
    - Enables individual cell voltage monitoring
    - Update receiver power board PCB layout and routing
    - Export updated netlists for all three boards
    - Add BMS reference image (bom/images/2S_BMS.jpg)
    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
    [receiver_board_power.kicad_pcb, receiver_board_power.kicad_sch]
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2026-01-25 Elininate dead space on right side of controller PCB
    [controller_board.kicad_pcb]
2026-01-26 Remove BMS and reorganize receiver boards for external charging
    Major schematic and layout revision based on EE review:
    - Remove BMS from receiver design; pivot to external LiPo charging
    - Reorganize components between power and logic boards:
    - Logic board: P-FET power switch, buck converter, UI (LED/button), debug UART
    - Power board: ESP32-C3, motor driver, battery monitoring
    - Add voltage dividers for 2S LiPo monitoring (B+ and BM)
    - Safe ADC voltages: B+ = 2.36V max, BM = 2.47V max
    - Add debug UART headers (GPIO20/21) for serial output when USB unavailable
    - Fix P-FET drain connection to properly power both buck and motor system
    - Update B2B connectors to dual 6-pin configuration (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
    [controller_board.kicad_pcb, receiver_board_logic.kicad_pcb, receiver_board_logic.kicad_sch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]
2026-01-28 Add battery monitoring module with unit tests and swap B+/BM GPIOs
    Add lib/battery.py for 2S LiPo voltage monitoring via hardware voltage
    dividers (B+ on GPIO0, BM on GPIO1). Includes per-cell voltage tracking,
    status detection (OK/LOW/CRITICAL/IMBALANCED), and percentage estimation.
    Add tests/test_battery.py with 25 unit tests covering voltage conversion,
    status thresholds, percentage clamping, cell imbalance, and edge cases.
    Update deploy scripts, documentation, and KiCad schematic/PCB to swap
    B+ and BM GPIO assignments for cleaner PCB routing.
    [receiver_board_power.kicad_pcb, receiver_board_power.kicad_sch]
2026-01-31 Investigating a SMD version of receiver board, so renaming existing projects with _th and reorganizing
    [controller_board_th.kicad_pcb, controller_board_th.kicad_sch, receiver_board_smd.kicad_pcb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]
2026-01-31 Add M2 mounting holes to receiver power board
    [receiver_board_th_logic.kicad_pcb, receiver_board_th_power.kicad_pcb, receiver_board_th_power.kicad_sch]
